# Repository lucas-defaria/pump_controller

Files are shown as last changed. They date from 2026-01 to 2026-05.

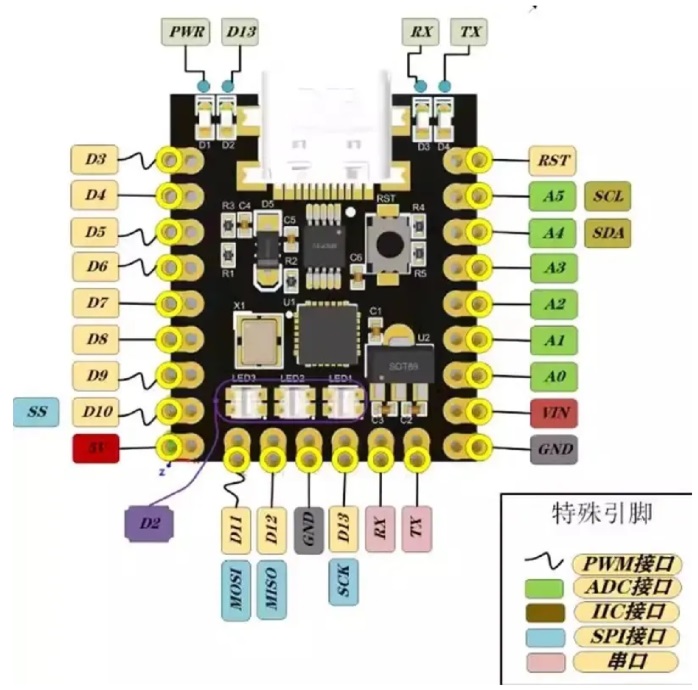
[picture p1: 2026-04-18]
hardware/EvoProject 1.0/0dc02c004ede8d6a5e8eab01bf967dcbca0c0e5b.jpeg

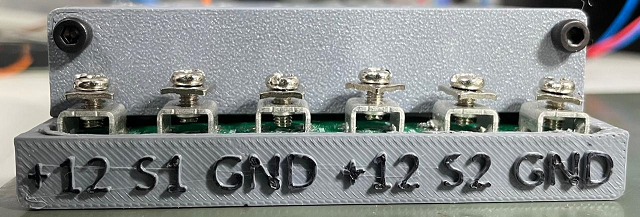
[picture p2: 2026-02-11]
saidas.png

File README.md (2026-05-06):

# PumpControl — Controle de Bomba de Combustível

Firmware para controle de bomba de combustível baseado em Arduino Nano, com dois modos de operação (MAP-based e slave por PWM externo) e proteção multinível por corrente, tensão e safety externa.

Este README descreve o estado atual do firmware no branch `main`.

## Visão geral

- **Modo MAP (default)**: pressão do MAP modulando duty entre 50% e 100% de Vsupply.
- **Modo slave (override)**: quando há PWM externo válido em D8, o duty externo é replicado nos outputs (anula o controle por MAP).
- **Proteção em 3 níveis** por corrente: NORMAL → FAULT → EMERGENCY.
- **Boot hold-off** de 2 s com motor OFF e inicialização defensiva (pinos em estado seguro antes de virar OUTPUT).
- **PWM de potência a 3.9 kHz** em Timer 0 (D5/D6), com compensação de timing em todo o código.

## Hardware

- **MCU**: Arduino Nano (ATmega328P @ 16 MHz)
- **Alimentação do módulo**: +5 V vindo da placa host entra no pino **5V (VOUT)** do Nano. **VIN desconectado** para evitar dropout do regulador interno (o DCDC da host já entrega 5 V regulado).
- **Power stage**: IRFB3077 como switch low-side, MBR30100 como freewheeling. Carga ligada entre VCC2 e PWM_OUT — o sinal medido no dreno é invertido em relação ao gate e só aparece quando há carga.
- **Driver de gate**: BC817 (NPN) + BC807 (PNP) — topologia inverte o sinal PWM, compensada em SW (`PWM_INVERTED_BY_HARDWARE = true`).
- **Sensores de corrente**: 2× **ACS758LCB-050B** (bidirecional ±50 A, 40 mV/A nominal). Correntes negativas (fluxo reverso) são clampadas a 0.
- **Sensor MAP**: MPX5700AP (pressão absoluta 15–700 kPa). Conversão para gauge subtraindo `ATMOSPHERIC_PRESSURE_BAR` (1.013 bar).
- **NTC 10 K** no dissipador, dividor com R19 (10 K) e R20 em série (alta impedância) para o ADC. C16 (4.7 μF) filtra.
- **Sense de Vsupply**: divisor 1:11 (R1=10 K, R2=1 K).
- **LED de status**: NeoPixel (1 LED) em D2.

## Pinout (Config.h)

| Pino | Função | Observações |
|---|---|---|
| A1 | NTC heatsink | Beta 3950, R25 = 10 K |
| A2 | Current Ch1 | ACS758LCB-050B |
| A3 | Current Ch2 | ACS758LCB-050B |
| A4 | MAP | MPX5700AP |
| A5 | Vsupply | Divisor 1/11 |
| D2 | NeoPixel | Status visual |
| D5 | PWM_OUT_2 | Timer 0 / OC0B |
| D6 | PWM_OUT_1 | Timer 0 / OC0A — movido de D3 (ver nota abaixo) |
| D7 | Safety input | OPTO output, ativo LOW (HIGH = OK) |
| D8 | PWM input externo | Slave mode (200–400 Hz) |
| A0 | AUX in | Reservado |

> **Por que D6 e D5 (Timer 0)** — o pino D11 (OC2A do Timer 2) é compartilhado com SPI/MOSI; quando o CAN/MCP2515 está ativo, ocorrem glitches periódicos no PWM em D3 (OC2B do mesmo Timer 2). Timer 0 não tem overlap com SPI, então mover ambas as saídas para D5/D6 elimina o problema.

> **R30 e R45 não populados** — D7 e D8 são apenas saídas dos OPTOs; não há caminho elétrico de retorno para a base de T4/T8. O Arduino é o **único driver** dos gates dos MOSFETs via D5/D6.

## PWM de potência

- **3.9 kHz** Phase-Correct PWM em Timer 0 (`16 MHz / (2 × 256 × 8) ≈ 3906 Hz`).
- Prescaler do Timer 0 alterado de 64 → 8 para atingir essa frequência.
- **Efeito colateral**: `millis()` e `delay()` rodam **8× mais rápido**. Todo código de timing usa o macro `MILLIS_COMPENSATED(ms)` (multiplica por `TIMER0_PRESCALER_FACTOR = 8`). `delayMicroseconds()` **não** é afetado.
- `PWM_INVERTED_BY_HARDWARE = true`: SW inverte o byte (`pwmValue = 255 - pwmValue`) antes do `analogWrite`, de forma que `duty = 1.0` corresponde a MOSFET ON (potência total).

## Modos de operação

### MAP mode (default)

Mapeamento linear entre pressão (gauge) e percentual da Vsupply:

| Pressão (bar gauge) | Saída |
|---|---|
| ≤ 0.4 (`MAP_BAR_LOW_SETPOINT`) | 50% Vsupply (`OUTPUT_PERCENT_MIN`) |
| 0.4 → 0.6 | interpolação linear |
| ≥ 0.6 (`MAP_BAR_HIGH_SETPOINT`) | 100% Vsupply (`OUTPUT_PERCENT_MAX`) |

Filtro EMA no MAP: `MAP_FILTER_ALPHA = 0.15`.

### Slave mode (PWM externo em D8)

Quando `ENABLE_EXTERNAL_PWM_MODE = true` e há sinal válido em D8, o controle por MAP é **sobrescrito**: o duty cycle medido na entrada vira o target dos outputs.

- Frequência válida: **200–400 Hz** (típico ~300 Hz)
- Timeout: **200 ms** sem pulso → volta para MAP
- Leitura via `pulseIn()` (pode bloquear até ~100 ms por amostra), uma medida por iteração do loop principal
- Linha de status no Serial muda para `*** EXTERNAL PWM MODE ***` com freq e duty medidos

## Proteção por corrente (3 níveis)

Estratégia: **nunca desligar totalmente em condição de fault** (motor sob carga seria danificado), exceto em EMERGENCY (curto/saturação).

| Nível | Faixa | Limite de tensão | Ação |
|---|---|---|---|
| **NORMAL** | < 40 A | 100% | Sem limitação |
| **FAULT** | ≥ 40 A | 50% | Reduz para mínimo seguro com rate limiting |
| **EMERGENCY** | ≥ 45 A | 0%* | Shutdown imediato, **bypassa rate limiting** e força `setDuty(0)` no main loop |

\* Se `ENABLE_EMERGENCY_SHUTDOWN = false`, EMERGENCY cai para 50% como fail-safe.

- Histerese: **2.5 A** para retornar ao nível anterior
- Decisão usa `max(I_ch1, I_ch2)` (qualquer canal acima do threshold dispara)
- Rate limiting normal: 0.05 por ciclo de 50 ms (≈ 1 s para varredura completa)
- Override de EMERGENCY no `loop()`: mesmo se source for slave, EMERGENCY força duty 0

## Proteção por tensão de alimentação

Adaptativa por queda percentual da Vsupply medida (lida em A5):

- **WARNING**: queda de 30%
- **CRITICAL**: queda de 50%
- Histerese: 0.5 V para evitar oscilação
- Faixa válida do sensor: 7.0–16.0 V (fora disso = sensor fault)

## Safety externa (D7)

- `ENABLE_EXTERNAL_SAFETY = true`
- `EXTERNAL_SAFETY_ACTIVE_HIGH = false` → **LOW = shutdown**, HIGH = OK (OPTO mantém HIGH em operação normal)
- **Bypassa rate limiting**: ação instantânea
- LED pisca azul (`updateExternalSafetyBlink`) enquanto ativo
- Skipa o restante do loop de controle (prioridade máxima)

## Sensor de corrente — calibração

ACS758LCB-050B (bidirecional, sensitivity nominal 40 mV/A):

- Calibração de slope feita em bancada (após filtro RC):
  - 1.32 A → 2.54 V
  - 2.30 A → 2.58 V
  - Slope = `(2.58 − 2.54) / (2.30 − 1.32) = 40.8 mV/A` ≈ nominal
- Vzero derivado do slope: **2.488 V @ 0 A** (offset Voe dentro do spec ±60 mV)
- Multi-amostragem: **32 samples × 50 μs ≈ 4.9 ms** (~19 ciclos de PWM a 3.9 kHz)
- EMA `CURRENT_FILTER_ALPHA = 0.05` (constante de tempo ~1 s a 20 Hz — agressivo para rejeitar ripple, lento o bastante para proteção)

## Temperatura (NTC 10K) — monitoramento

- Equação Beta: `1/T = 1/T25 + (1/β) · ln(R / R25)`, β = 3950
- Mesmo rail (+5 V) para divisor e ADC → `Vref` cancela: `R_NTC = R_PULLUP × adc / (1023 − adc)`
- Detecção de falha: temp fora de [-40, 150] °C indica sensor aberto/curto
- **Sem ação de proteção** — apenas leitura e log no status report

## LED de status (NeoPixel em D2)

| Cor | Significado |
|-----|---|
| Verde sólido | Normal (gradiente verde→vermelho conforme corrente sobe) |
| Vermelho 1 Hz | FAULT |
| Vermelho 5 Hz | EMERGENCY |
| Azul piscando | Safety externa ativa |

## Comunicação

- **Serial @ 115200 bps**:
  - Linha compacta a 20 Hz com modo (MAP/EXTERNAL PWM), pressão ou duty externo, target, Vsupply, I1, I2, voltage limit, nível de proteção
  - Relatório detalhado a 1 Hz com todas as métricas, fault counts e estado dos inputs digitais
- **CAN bus (MCP2515)**: stub presente (`g_can.poll()`), infra mínima — sem tráfego ativo nesta versão do `main`. Versão com CAN funcional segue em `develop-TempControl`.

## Sequência de boot

1. `PowerOutputs::begin()` força os pinos em estado seguro (HIGH = MOSFET OFF na topologia invertida) ainda como INPUT
2. Configura como OUTPUT após estabilização (100 μs)
3. Configura Timer 0 (Phase-Correct, prescaler 8) para 3.9 kHz
4. `setDuty(0)` + 100 ms de grace period
5. Inicialização dos sensores e da safety externa
6. **Hold-off de 2 s** com motor OFF (`delayMicroseconds(2_000_000)` — não afetado pelo prescaler)
7. Entra no loop normal

## Configuração — flags principais (Config.h)

| Flag | Default | Função |
|---|---|---|
| `ENABLE_HIGH_FREQ_PWM` | `true` | 3.9 kHz no Timer 0 |
| `PWM_INVERTED_BY_HARDWARE` | `true` | Compensa BC817+BC807 |
| `ENABLE_EMERGENCY_SHUTDOWN` | `true` | 0% em EMERGENCY (false = 50%) |
| `ENABLE_EXTERNAL_SAFETY` | `true` | D7 LOW desliga |
| `EXTERNAL_SAFETY_ACTIVE_HIGH` | `false` | Polaridade da safety |
| `ENABLE_EXTERNAL_PWM_MODE` | `true` | Slave mode em D8 |

Ajustes finos: setpoints de pressão (`MAP_BAR_*_SETPOINT`), thresholds de corrente (`CURRENT_THRESHOLD_*`), faixa válida do sensor (`VOLTAGE_*_VALID`), filtros EMA.

## Build

- Arduino IDE 1.8+ ou PlatformIO
- Lib: `Adafruit_NeoPixel`
- Board: Arduino Nano (ATmega328P, Old Bootloader)
- Sketch: `src/PumpControl/PumpControl.ino`

## Notas da PCB v1.0

- 5 V da host alimenta o Nano via pino 5V (VOUT); VIN deixado desconectado para evitar dropout do regulador interno
- Conectores CN4 e CN5 podem estar com pinagem invertida
- Sensor MAP: Vout é o **pino 1** (não pino 3)
- Pode ser necessário remover componentes do pino RESET durante gravação
- Trilha de 5 V do USB do Arduino deve ser cortada para evitar alimentação reversa
- PWM_OUT_1 movido de D3 → **D6** para resolver glitches por compartilhamento de Timer 2 com SPI

## Estrutura do firmware

```
src/PumpControl/
├── PumpControl.ino       — main loop, source select, override de EMERGENCY
├── Config.h              — todos os parâmetros de compile-time
├── MapSensor.{h,cpp}     — MPX5700AP, conversão absoluta → gauge, EMA
├── PowerOutputs.{h,cpp}  — Timer 0 PWM, inversão por HW, voltage limiting
├── CurrentSensor.{h,cpp} — ACS758LCB-050B, multi-sampling, EMA
├── PowerProtection.h     — máquina de estados NORMAL/FAULT/EMERGENCY
├── VoltageSensor.{h,cpp} — divisor 1:11, leitura de Vsupply
├── VoltageProtection.h   — proteção por queda percentual
├── TempSensor.h          — NTC 10K, equação Beta (monitoramento)
├── PwmInput.h            — pulseIn-based, slave mode em D8
├── StatusLed.h           — NeoPixel state machine
└── CanInterface.{h,cpp}  — stub MCP2515
```

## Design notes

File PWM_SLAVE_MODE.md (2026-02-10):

# Modo Slave PWM - Documentação

## Visão Geral

Foi implementado um modo secundário de operação onde a placa pode funcionar como "slave", reproduzindo um sinal PWM externo nas suas saídas, ao invés de usar o controle baseado no sensor MAP.

## Funcionamento

### Modo Normal (MAP-based)
- **Quando**: Nenhum sinal PWM válido detectado na entrada digital PIN 1 (D7)
- **Comportamento**: Sistema opera normalmente lendo o sensor MAP e controlando as bombas baseado na pressão medida
- **Este é o modo padrão quando não há sinal PWM**

### Modo Slave (PWM Replication)
- **Quando**: Sinal PWM válido detectado na entrada digital PIN 1 (D7)
- **Comportamento**: Sistema replica o duty cycle do PWM de entrada nas duas saídas
- **Transição automática**: Sistema detecta automaticamente quando há sinal PWM válido e muda para modo slave
- **Retorno automático**: Se o sinal PWM desaparecer por mais de 200ms, retorna ao modo normal MAP

## Características Técnicas

### Hardware
- **Pino de entrada**: D7 (PIN_DIG_IN_1 / Config::PIN_PWM_INPUT)
- **Frequência esperada**: 25Hz (aceita 15-35Hz)
- **Duty cycle**: 0-100% (variável)
- **Timeout**: 200ms sem pulso válido = sinal perdido

### Proteções Mantidas
Mesmo em modo slave, todas as proteções continuam ativas:
- ? Proteção de corrente (current protection)
- ? Proteção de tensão (voltage protection)
- ? External safety input (D8)
- ? Rate limiting
- ? Status LED indicando corrente e falhas

### Prioridade de Controle
1. **MAIS ALTA**: External Safety Input (D8) - desliga tudo imediatamente
2. **MÉDIA**: PWM Slave Mode - se sinal válido presente
3. **NORMAL**: MAP-based Control - modo padrão quando não há sinal PWM

## Configuração

Todas as configurações estão em [Config.h](Config.h):

```cpp
// Habilitar/desabilitar modo slave
constexpr bool ENABLE_PWM_SLAVE_MODE = true;

// Pino de entrada PWM
constexpr uint8_t PIN_PWM_INPUT = PIN_DIG_IN_1;  // D7

// Faixa de frequência válida (Hz)
constexpr float PWM_INPUT_FREQ_MIN = 15.0f;
constexpr float PWM_INPUT_FREQ_MAX = 35.0f;

// Timeout para perda de sinal (ms)
constexpr unsigned long PWM_INPUT_TIMEOUT_MS = 200;
```

## Detalhes de Implementação

### Classe PwmInput

Nova classe criada em [PwmInput.h](PwmInput.h) que implementa:
- Leitura precisa de PWM por detecção de bordas (rising/falling edge)
- Cálculo automático de frequência e duty cycle
- Validação de sinal (frequência dentro da faixa esperada)
- Timeout automático quando sinal desaparece
- Usa `micros()` para máxima precisão de timing

### Métodos Principais

```cpp
g_pwmInput.update();              // Atualizar leitura (chamar frequentemente)
g_pwmInput.isSignalValid();       // Verificar se sinal PWM válido presente
g_pwmInput.getDutyCycle();        // Obter duty cycle (0.0 a 1.0)
g_pwmInput.getFrequency();        // Obter frequência detectada (Hz)
```

## Output Serial

### Modo Normal
```
P:0.45bar | Vs:12.3V | T%:85% | Vo:10.5V | I1:12.3A | I2:11.8A | Lim:100% | NORMAL
```

### Modo Slave (novo)
```
*** SLAVE MODE *** | PWM In:75.5% @ 25.2Hz | Vs:12.3V | Vo:9.3V | I1:12.3A | I2:11.8A | Lim:100% | NORMAL
```

### Status Report Detalhado
Quando em modo slave, o status report mostra informações adicionais:
```
PWM Slave Mode:  *** ACTIVE ***
  Input Duty:    75.5 %
  Input Freq:    25.12 Hz
  Period:        39.81 ms
  High Time:     30.06 ms
```

## Testes Recomendados

1. **Teste sem sinal**: Verificar que sistema opera normalmente em modo MAP
2. **Teste com PWM 25Hz**: Aplicar PWM de 25Hz e verificar mudança para modo slave
3. **Teste de duty cycle variável**: Variar duty cycle de 10% a 90% e verificar que saídas acompanham
4. **Teste de timeout**: Remover sinal PWM e verificar retorno ao modo MAP após 200ms
5. **Teste de proteções**: Verificar que proteções de corrente/tensão continuam funcionando em modo slave
6. **Teste de frequência fora da faixa**: Aplicar PWM de 10Hz ou 40Hz e verificar que sistema ignora (permanece em modo MAP)

## Notas Importantes

- ?? **Não altera comportamento padrão**: Sistema continua funcionando normalmente quando não há sinal PWM
- ?? **Detecção automática**: Não precisa configurar manualmente, sistema detecta presença de sinal
- ?? **Proteções sempre ativas**: Mesmo em modo slave, todas as proteções (corrente, tensão) permanecem operantes
- ?? **External safety tem prioridade**: Input de segurança externa (D8) sempre tem prioridade sobre tudo
- ? **Transição suave**: Mudança entre modos é suave graças ao rate limiting existente
- ? **Compatível com timer modificado**: Usa `micros()` que não é afetado pela modificação do Timer 0

## Arquivos Modificados

1. **PwmInput.h** (novo) - Classe para leitura de PWM
2. **Config.h** - Adicionadas configurações de PWM slave
3. **PumpControl.ino** - Integração do modo slave no loop principal

## Histórico

- **2025-02-02**: Implementação inicial do modo slave PWM

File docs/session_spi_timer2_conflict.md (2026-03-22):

# Sessão: Conflito SPI/Timer 2 - PWM D3 resetando periodicamente

## Problema
Com o CAN bus ativo (MCP2515 via SPI), a saída PWM no pino D3 (OC2B, Timer 2) reseta para 0% duty periodicamente. D5 (OC0B, Timer 0) funciona perfeitamente com o mesmo valor de PWM.

## Causa raiz identificada
**SPI e Timer 2 compartilham o pino D11 (PB3 = MOSI = OC2A).** Transações SPI do MCP2515 interferem com o Timer 2, corrompendo a saída hardware OC2B no D3. No PumpController original, o CanInterface era um stub vazio sem comunicação SPI real - por isso nunca houve problema.

### Evidências
- Comentando `g_can.poll()`: D3 funciona perfeitamente (sem SPI = sem interferência)
- D5 (Timer 0) nunca apresenta o problema (Timer 0 não compartilha pinos com SPI)
- Com dados CAN reais a 50Hz: problema menos perceptível mas ainda presente no osciloscópio
- Com SavvyCAN a 500ms: problema visível com ciclo bem definido

## Tentativas de solução

### 1. Mover PWM para Timer 0 (D6) - FUNCIONA mas hardware é fixo
- Alterar `PIN_PWM_OUT_1 = 6` (OC0A, Timer 0) no Config.h
- Ambas saídas ficariam no Timer 0, sem conflito com SPI
- **Descartado**: PCB tem trilhas fixas em D3 e D5

### 2. Desabilitar SPI entre transações - PARCIAL
```cpp
// Em CanInterface::poll():
SPCR |= _BV(SPE);   // Habilita SPI antes
// ... checkReceive / readMsgBuf ...
SPCR &= ~_BV(SPE);  // Desabilita SPI depois
```
- Reduziu o problema (dados reais a 50Hz pareciam OK visualmente)
- Ainda apresenta glitches breves durante a transação SPI (~40µs)

### 3. Restaurar COM2B1 após poll - PARCIAL
```cpp
TCCR2A |= _BV(COM2B1);  // Reconecta Timer 2 ao D3 após SPI
```
- Combinado com solução 2, ajudou mas não eliminou completamente

### 4. Software PWM via ISR do Timer 2 - IMPLEMENTADO (ainda com problema de reset)
Abordagem: não usar saída hardware OC2B, controlar D3 via PORTD nas ISRs do Timer 2.

**PowerOutputs.h:**
- `extern volatile bool g_timer2_softpwm;` (declaração)
- Em `begin()`: `TCCR2A &= ~(_BV(COM2B1) | _BV(COM2B0));` desconecta OC2B
- Em `begin()`: `TIMSK2 |= _BV(OCIE2B) | _BV(TOIE2);` habilita interrupções
- Em `setDuty()`: para D3, escreve OCR2B e controla flag ao invés de analogWrite

**PumpControl.ino:**
```cpp
volatile bool g_timer2_softpwm = false;

ISR(TIMER2_OVF_vect) {
    // BOTTOM: set D3 HIGH (início do ciclo PWM)
    if (g_timer2_softpwm) {
        PORTD |= _BV(PD3);
    }
}

ISR(TIMER2_COMPB_vect) {
    // Compare match (up e down): toggle D3
    if (g_timer2_softpwm) {
        PORTD ^= _BV(PD3);
    }
}
```

**Lógica do toggle:**
- BOTTOM → OVF ISR → força HIGH
- Up-count match → COMPB ISR → toggle HIGH→LOW
- Down-count match → COMPB ISR → toggle LOW→HIGH
- Replica comportamento Phase-Correct PWM não-invertido

**Status:** Compila com erro de definição múltipla da variável `g_timer2_softpwm` (resolvido com `extern`), mas o **problema de reset do PWM persiste**. A interferência do SPI pode estar afetando o próprio contador do Timer 2 (TCNT2), não apenas a saída OC2B.

## Arquivos modificados nesta sessão

| Arquivo | Mudanças |
|---|---|
| `Config.h` | `TEMP_FAN_OFF_C`: 95→50, `PIN_CAN_CS`: 10→9 |
| `CanInterface.cpp` | Removido workaround SPI enable/disable (substituído por ISR) |
| `PowerOutputs.h` | Software PWM via ISR para D3, `extern volatile bool g_timer2_softpwm` |
| `PumpControl.ino` | Adicionadas ISRs Timer 2 (OVF + COMPB), definição `g_timer2_softpwm` |

## Próximos passos a investigar

1. **Verificar se SPI corrompe TCNT2** (não apenas OC2B): se o contador do Timer 2 é afetado, as ISRs também terão timing errado
2. **Mover D3 para Timer 1**: usar ICR1 como TOP e OC1A/OC1B - Timer 1 não compartilha pinos com SPI. Mas D9 (OC1A) é CAN CS e D10 (OC1B) tem pull-down do módulo
3. **Timer 1 com ISR para D3**: usar Timer 1 compare interrupt para gerar software PWM no D3, eliminando completamente o Timer 2 da equação
4. **Verificar se NeoPixel (D2, PORTD) contribui**: NeoPixel escreve PORTD inteiro durante show(), D3 é PD3. Com COM2B desconectado e ISR controlando via PORTD, o NeoPixel pode sobrescrever o estado de D3
5. **Testar desabilitando NeoPixel**: comentar `g_statusLed.updateFromCurrent()` para isolar se o NeoPixel está sobrescrevendo D3 via PORTD

### Hipótese mais provável: conflito NeoPixel + Software PWM
Com a solução de ISR (software PWM via PORTD), o NeoPixel `show()` pode estar causando o problema:
- NeoPixel D2 está no PORTD (PD2)
- `show()` faz `hi = PORTD | pinMask; lo = PORTD & ~pinMask;` e depois escreve `hi`/`lo` repetidamente para PORTD inteiro via assembly
- Com hardware OC2B, o timer overrides PORTD → NeoPixel não afeta D3
- Com software PWM via PORTD, NeoPixel `show()` pode sobrescrever PD3 durante os ~30µs de transmissão (interrupts desabilitados com `cli()`)
- **Isso causaria glitches no D3 a cada chamada de `updateFromCurrent()`** (a cada 50ms do loop)

## Contexto do hardware
- Arduino Nano (ATmega328P)
- MCP2515 + TJA1050 (CAN bus 500kbps, cristal 8MHz)
- SPI: MOSI=D11, MISO=D12, SCK=D13, CS=D9
- PWM saídas: D3 (Timer 2 OC2B), D5 (Timer 0 OC0B)
- NeoPixel: D2 (PORTD)
- Driver inversor: BC817+BC807 (PWM_INVERTED_BY_HARDWARE = true)
- Timer 0 prescaler: 64→8 (millis() 8x mais rápido, compensado com MILLIS_COMPENSATED)
- PWM frequência: 3.9kHz Phase-Correct

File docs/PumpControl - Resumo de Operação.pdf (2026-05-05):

# Modulo PumpControl - Resumo de Operacao

Documento de referencia para teste em campo. Numeracao dos pinos conforme conector Molex Mini-Fit Jr. de 16 vias da traseira do modulo.

## 1. Modo MAP (operacao padrao)

O modulo le o sensor de pressao MPX5700AP e ajusta a saida em funcao da pressao (em bar relativos a atmosfera):

Pressao lida | Saida na bomba
≤ 0,4 bar | 50% da tensao de alimentacao
0,6 bar ou mais | 100% da tensao de alimentacao
Entre 0,4 e 0,6 bar | Rampa linear entre 50% e 100%

A saida e proporcional a tensao medida (nao fixa em 12 V), entao o modulo se adapta automaticamente em qualquer faixa de 8 V a 14,5 V.

## 2. Modo Slave (PWM externo)

O modulo monitora o pino 13 do conector.
Se receber um sinal PWM valido entre 200 e 400 Hz (tipico 300 Hz, nivel logico 0–12 V), automaticamente sai do modo MAP e passa a copiar o duty cycle desse sinal nas duas saidas para a bomba.
Se o sinal sumir por mais de 200 ms, o modulo volta sozinho ao modo MAP.
Nao ha chave fisica: o "switch" e automatico, baseado na presenca/ausencia do PWM no pino 13 .

## 3. Protecoes (em ordem de prioridade)

05/05/2026, 20:13 | PumpControl - Resumo de Operação

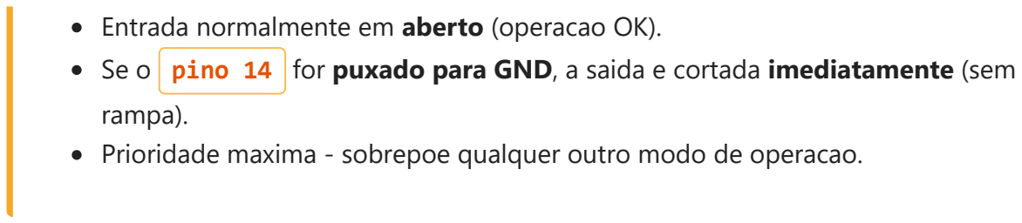
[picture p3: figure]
rampa).

Entrada normalmente em aberto (operacao OK).
Se o pino 14 for puxado para GND, a saida e cortada imediatamente (sem

Prioridade maxima - sobrepoe qualquer outro modo de operacao.

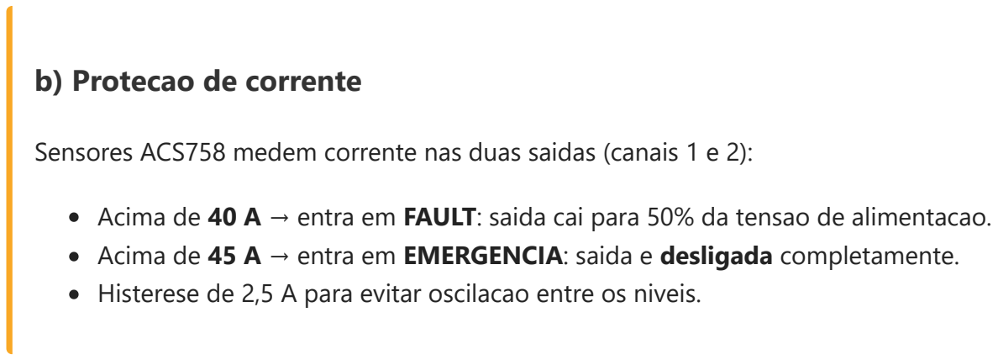
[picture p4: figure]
b) Protecao de corrente

Sensores ACS758 medem corrente nas duas saidas (canais 1 e 2):

Acima de 40 A → entra em FAULT: saida cai para 50% da tensao de alimentacao. Acima de 45 A → entra em EMERGENCIA: saida e desligada completamente. Histerese de 2,5 A para evitar oscilacao entre os niveis.

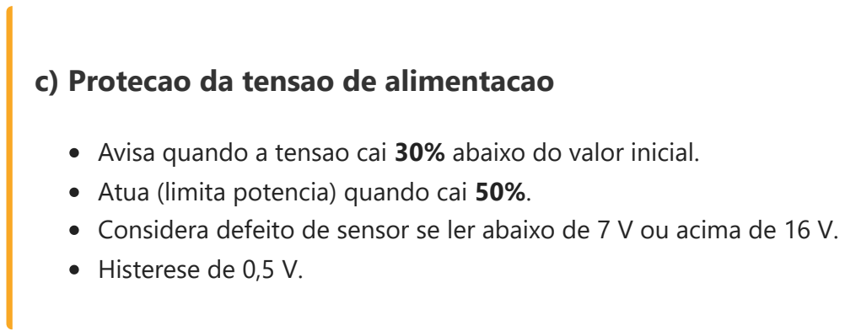
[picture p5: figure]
c) Protecao da tensao de alimentacao; Atua (limita potencia) quando cai 50%.; Histerese de 0,5 V.

Avisa quando a tensao cai 30% abaixo do valor inicial.

Considera defeito de sensor se ler abaixo de 7 V ou acima de 16 V.

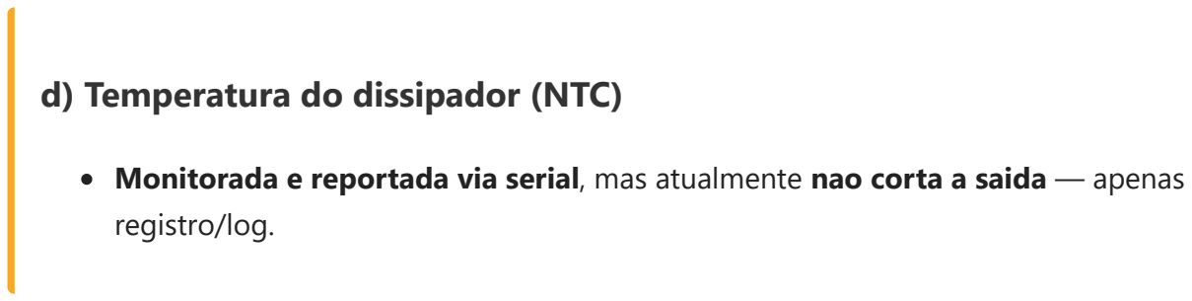
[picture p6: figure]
d) Temperatura do dissipador (NTC); registro/log.

Monitorada e reportada via serial, mas atualmente nao corta a saida — apenas

## 4. Indicacao no LED (NeoPixel)

Verde → operacao normal (cor passa de verde para vermelho conforme a corrente sobe). Vermelho piscando 1 Hz → FAULT de corrente (acima de 40 A).
Vermelho piscando 5 Hz → EMERGENCIA (acima de 45 A).
Azul piscando → Safety externa ativa ( pino 14 em GND).

## 5. Partida segura

file:///C:/Users/lucas.faria/Documents/Proj/pump_controller/docs/resumo_cliente.html | 2/4

Ao energizar, a saida fica forcada em 0% por aproximadamente 2 segundos enquanto os sensores estabilizam.
So depois desse intervalo o controle normal entra em operacao.

## 6. Pinagem do conector (vista traseira)

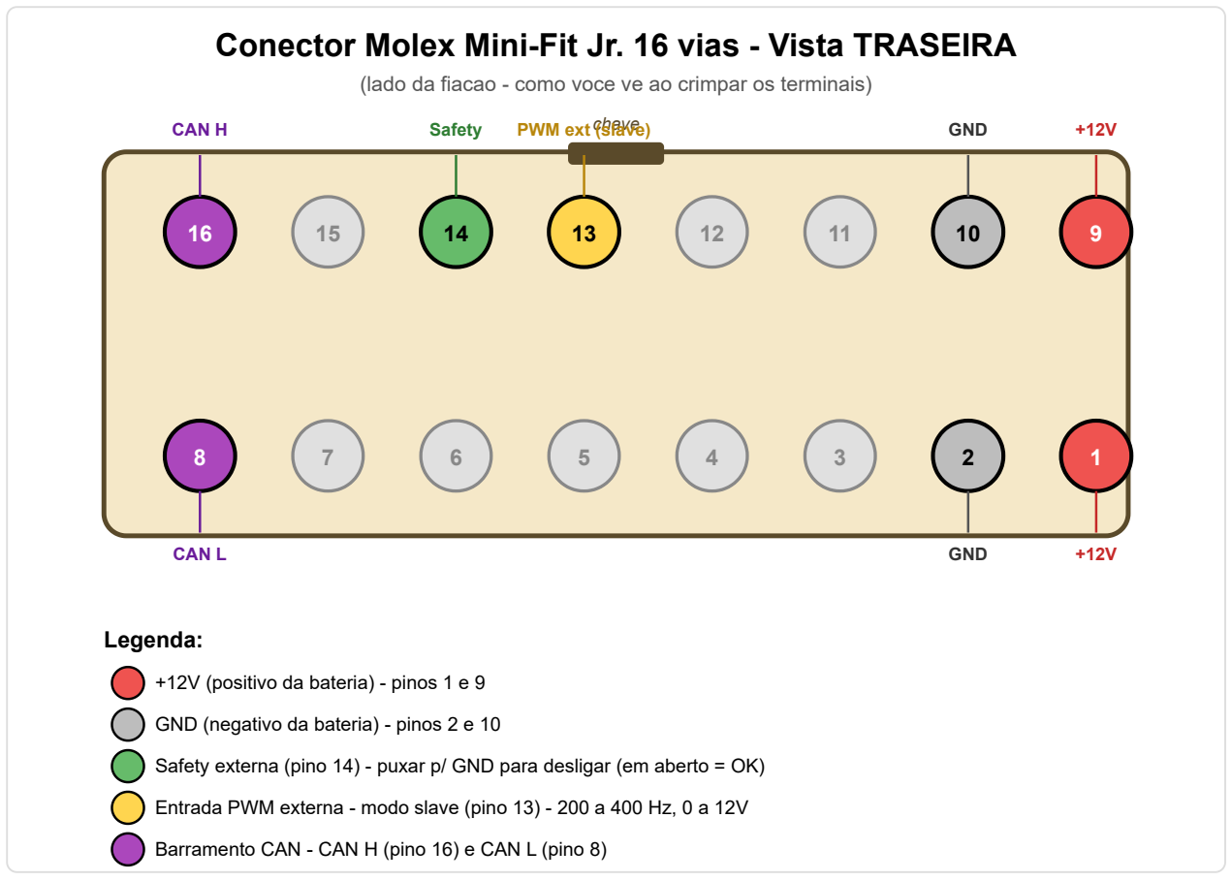
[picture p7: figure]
chave; CAN H; Safety; PWM ext (slave); GND; CAN L; Legenda:

Conector Molex Mini-Fit Jr. 16 vias - Vista TRASEIRA

(lado da fiacao - como voce ve ao crimpar os terminais)

+12V (positivo da bateria) - pinos 1 e 9

GND (negativo da bateria) - pinos 2 e 10

Safety externa (pino 14) - puxar p/ GND para desligar (em aberto = OK)

Entrada PWM externa - modo slave (pino 13) - 200 a 400 Hz, 0 a 12V

Barramento CAN - CAN H (pino 16) e CAN L (pino 8)

Tabela resumida

Pino | Funcao
1, 9 | +12V (positivo da bateria)
2, 10 | GND (negativo da bateria)

8 CAN L

13 Entrada PWM externa (modo slave)

14 Safety externa (em aberto = OK / GND = desliga)

16 CAN H

file:///C:/Users/lucas.faria/Documents/Proj/pump_controller/docs/resumo_cliente.html | 3/4

Pino | Funcao
3, 4, 5, 6, 7, 11, 12, 15 | Nao utilizados (deixar desconectados)

PumpControl - Documento de referencia para teste em campo

file:///C:/Users/lucas.faria/Documents/Proj/pump_controller/docs/resumo_cliente.html | 4/4

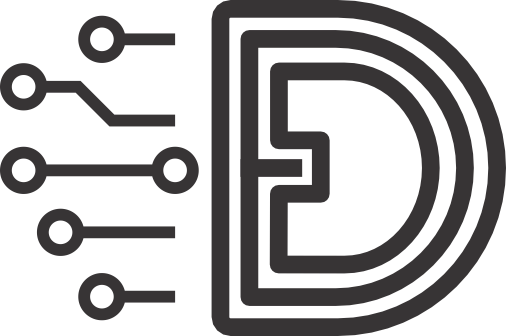
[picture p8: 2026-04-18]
hardware/EvoProject 1.0/Sem título-1.png

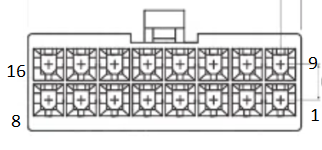
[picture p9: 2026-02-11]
image.png

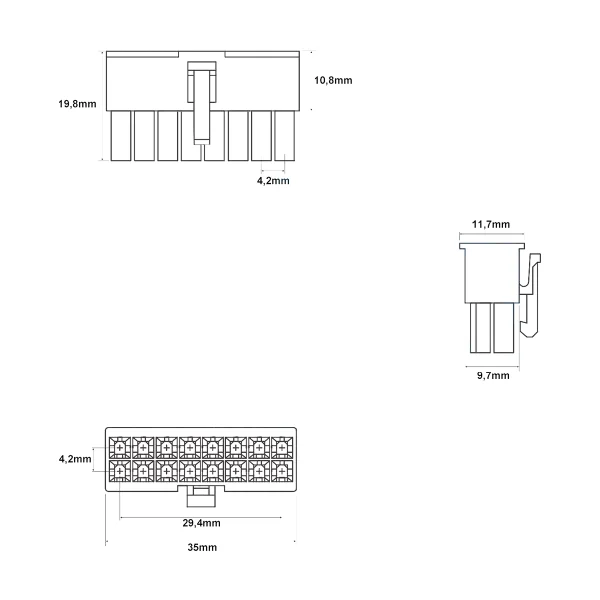
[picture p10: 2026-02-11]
02-conector-mini-fit-macho-hm051-2x8-16-vias.webp

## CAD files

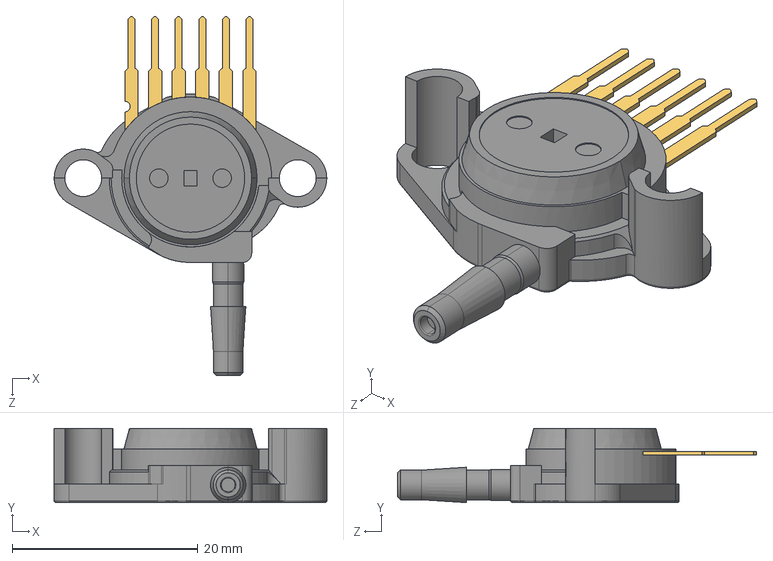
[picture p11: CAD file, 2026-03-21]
hardware/EvoProject 1.0/MPX5700AP.stp
29.4 x 8.01 x 38.7 mm

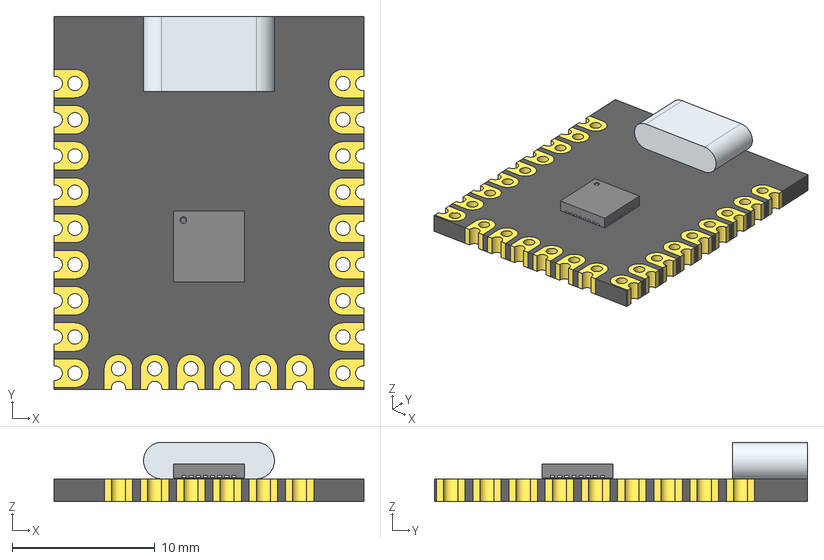
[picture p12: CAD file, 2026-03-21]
hardware/EvoProject 1.0/Arduino_Nano_SuperMini.stp
21.7 x 26.2 x 4.16 mm

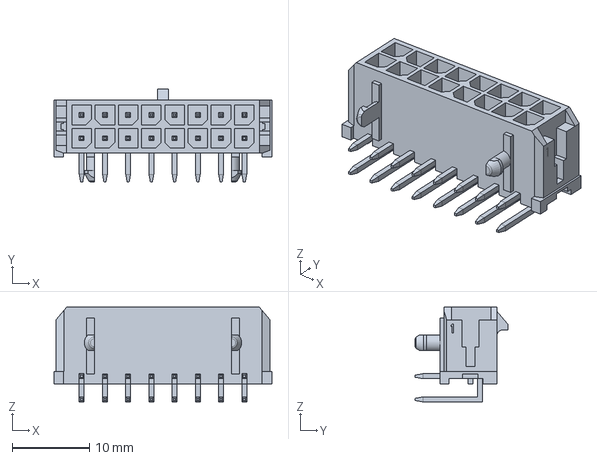
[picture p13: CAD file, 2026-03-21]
hardware/EvoProject 1.0/430451600.stp
28.1 x 11.9 x 12.2 mm

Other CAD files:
hardware/EvoProject 1.0/Arduino_Nano_SuperMicro.step

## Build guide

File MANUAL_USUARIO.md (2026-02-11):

# Manual do Usuário - PumpControl

## Especificações Técnicas

### Alimentação
- **Tensão de entrada:** 8-16V DC (sistema automotivo)
- **Consumo:** Variável conforme carga conectada

### Sensor de Pressão (MAP)
- **Range de operação:** 15-700 kPa absoluto (0.15 - 7bar) (gauge/relativo)
- **Tipo:** MPX5700AP (pressão absoluta, convertida para gauge)

### Saídas PWM
- **Canais:** 2 saídas independentes
- **Controle:** Percentual da tensão de alimentação
  - Pressão baixa (0.4 bar): 70% da tensão de entrada
  - Pressão alta (0.6 bar): 100% da tensão de entrada
  - Valores intermediários: interpolação linear

### Monitoramento de Corrente
- **Canais:** 2 sensores independentes (ACS772LCB-050B)
- **Range:** 0-50A Maxima medida pelo sensor por canal (unidirecional)

---

## Conector de Interface



### Pinagem do Conector - vista traseira

| Pino | Função |
|---|---|
| 1 | VCC (Alimentação +8-16V) |
| 2 | GND (Terra) |
| 3 | |
| 4 | |
| 5 | |
| 6 | |
| 7 | |
| 8 | |
| 9 | |
| 10 | |
| 11 | |
| 12 | |
| 13 | |
| 14 | |
| 15 | Desliga saída (Safety) aciona por negativo |
| 16 |  |

saidas

#### +12 = +Bateria
#### S1 S2 = Saída para bomba 1 e 2 - acionamento por negativo
#### GND = Negativo bateria
---

## Sistema de Proteção por Corrente

O sistema possui proteção progressiva que **nunca desliga completamente** a bomba (crítico para motor em funcionamento).

### Níveis de Proteção

| Corrente | Nível | Ação | Redução de Potência |
|---|---|---|---|
| 0-25A | **NORMAL** | Operação normal | 0% (potência plena) |
| 25-30A | **WARNING** | Alerta inicial | 30% de redução |
| 30-35A | **HIGH** | Corrente alta | 40% de redução |
| 35-40A | **CRITICAL** | Corrente crítica | 50% de redução |
| >40A | **FAULT** | Falha detectada | 50% mantido (mínimo seguro) |
| >45A | **EMERGENCY** | Emergência | Desligamento completo* |

> *EMERGENCY: Indica curto-circuito ou sobrecarga severa (sensor próximo ao limite de 50A)

---

## Indicação Visual - LED RGB

O LED indica o estado do sistema em tempo real pela cor e comportamento:

### Cores Sólidas (operação normal)
| Cor | Significado |
|-----|---|
| ?? **Verde** | Corrente baixa (0-25A) - operação normal |
| ?? **Verde?Amarelo** | Corrente moderada (25-30A) - entrando em warning |
| ?? **Amarelo?Laranja** | Corrente elevada (30-35A) - proteção ativa |
| ?? **Laranja?Vermelho** | Corrente alta (35-40A) - proteção crítica |

### Piscando (situações críticas)
| Comportamento | Significado | Ação Necessária |
|---|---|---|
| ?? **Pisca lento** (1Hz) | FAULT - Corrente >40A | Verificar carga/fiação |
| ?? **Pisca rápido** (5Hz) | EMERGENCY - Corrente >45A | Verificar curto-circuito |
| ?? **Pisca azul** (2Hz) | Desligamento por segurança externa | Verificar entrada D8 |

---

## Entrada de Segurança Externa Pino 15

### Função
Permite que sistemas externos (ECU, relé de segurança, etc.) desliguem imediatamente as saídas.

### Configuração
- **Pino:** 15 (ativo em LOW - pull-up interno)
- **Ação:** Quando ativada, força saídas para 0V imediatamente
- **Indicação:** LED pisca em azul enquanto ativa

### Comportamento
- Quando a entrada de segurança é acionada:
  1. Saídas PWM vão para 0% instantaneamente (sem rampa)
  2. LED pisca em azul
  3. Mensagem no serial: "EXTERNAL SAFETY ACTIVE"
  4. Sistema retoma operação normal quando entrada é liberada

---

---

## Observações Importantes

### ?? Proteção Crítica
- O sistema **NUNCA** desliga completamente a bomba em níveis NORMAL-FAULT
- Apenas em EMERGENCY (>45A) ocorre desligamento completo
- Proteção progressiva reduz corrente gradualmente

### ?? Operação Normal
- LED verde = tudo OK
- Transição de cores = sistema adaptando à carga
- Corrente típica: 15-25A em operação normal

### ?? Atenção Necessária
- LED piscando vermelho = verificar carga e fiação
- LED piscando azul = entrada de segurança ativa
- Corrente >30A = investigar causa

### ?? Adaptação Automática
- Sistema ajusta saída baseado em:
  1. Pressão MAP (0.4-0.6 bar)
  2. Tensão de alimentação (8-16V)
  3. Corrente monitorada (proteção)
  
- Saída é sempre um **percentual da tensão de entrada**
- Exemplo: 80% em 12V = 9.6V / 80% em 14V = 11.2V

---

## Resumo - O que Observar

? **Normal:** LED verde sólido, corrente <25A  
?? **Atenção:** LED amarelo/laranja, corrente 25-35A  
?? **Crítico:** LED vermelho ou piscando, corrente >35A  
?? **Segurança:** LED azul piscando, entrada D8 ativa

---

*Versão do firmware: Baseada em Config.h com proteção progressiva*

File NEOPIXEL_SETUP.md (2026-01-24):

# Configuração do LED NeoPixel - Status Visual

## Descrição
O sistema agora inclui um LED NeoPixel RGB no pino D2 para indicação visual do estado de carga do motor baseado na pressão MAP.

### Indicação de Cores:
- **?? VERDE**: Baixa carga (MAP ? 0.2 bar)
- **?? AMARELO/LARANJA**: Carga média (MAP entre 0.2 e 0.4 bar) - transição gradual
- **?? VERMELHO**: Alta carga (MAP ? 0.4 bar - setpoint superior)

A cor muda gradualmente entre verde e vermelho conforme a pressão MAP aumenta, proporcionando feedback visual em tempo real da carga do motor.

## Hardware

### Conexões:
- **Pino D2**: Conectado ao DATA IN do LED NeoPixel
- **5V**: Alimentação do NeoPixel
- **GND**: Terra comum

### LED Suportado:
- WS2812B / NeoPixel compatível
- Configurado para 1 LED (pode ser ajustado em Config.h)

## Instalação da Biblioteca

### Método 1: Arduino IDE
1. Abra o Arduino IDE
2. Vá em **Sketch** ? **Include Library** ? **Manage Libraries...**
3. Pesquise por **"Adafruit NeoPixel"**
4. Clique em **Install** na biblioteca "Adafruit NeoPixel" by Adafruit
5. Aguarde a instalação completar

### Método 2: PlatformIO
Adicione ao seu `platformio.ini`:
```ini
lib_deps =
    adafruit/Adafruit NeoPixel@^1.12.0
```

## Arquivos Modificados/Criados

### Novos Arquivos:
- `StatusLed.h` - Classe de controle do LED NeoPixel

### Arquivos Modificados:
- `Config.h` - Adicionadas configurações:
  - `PIN_STATUS_LED` (D2)
  - `STATUS_LED_COUNT` (1)
  - `LED_BRIGHTNESS` (50 = ~20% do brilho máximo)
  
- `PumpControl.ino`:
  - Adicionado include `StatusLed.h`
  - Criada instância global `g_statusLed`
  - Inicialização no `setup()`
  - Atualização no `loop()` a cada ciclo (20Hz)

## Configuração

Todas as configurações estão em `Config.h`:

```cpp
// Pino do LED NeoPixel
constexpr uint8_t PIN_STATUS_LED = 2;  // D2

// Quantidade de LEDs na tira/anel
constexpr uint16_t STATUS_LED_COUNT = 1;

// Brilho (0-255, recomendado 30-100)
constexpr uint8_t LED_BRIGHTNESS = 50;
```

## Como Funciona

A classe `StatusLed` utiliza os mesmos setpoints de pressão MAP definidos em `Config.h`:
- `MAP_BAR_LOW_SETPOINT` (0.2 bar) - Verde
- `MAP_BAR_HIGH_SETPOINT` (0.4 bar) - Vermelho

Entre esses valores, o LED faz uma interpolação linear:
- Componente **RED**: Aumenta de 0 para 255
- Componente **GREEN**: Diminui de 255 para 0
- Componente **BLUE**: Permanece em 0

## Solução de Problemas

### LED não acende:
1. Verifique as conexões (DATA, 5V, GND)
2. Confirme que a biblioteca Adafruit NeoPixel está instalada
3. Verifique se o pino D2 não está sendo usado por outra função
4. Teste aumentar `LED_BRIGHTNESS` para 100 em Config.h

### LED com cor errada:
1. Alguns NeoPixels usam ordem diferente (RGB vs GRB)
2. Modifique em `StatusLed.h` linha 13:
   ```cpp
   // Tente trocar NEO_GRB por NEO_RGB se as cores estiverem trocadas
   : _strip(numPixels, pin, NEO_GRB + NEO_KHZ800) {}
   ```

### LED piscando/instável:
1. Adicione um capacitor 1000µF entre 5V e GND perto do LED
2. Adicione um resistor 470? entre D2 e DATA IN do LED

## Personalização

### Mudar cores:
Edite o método `updateFromPressure()` em `StatusLed.h`:
```cpp
// Exemplo: Azul para baixa carga, Amarelo para alta
if (pressureBar <= pLow) {
    red = 0; green = 0; blue = 255;  // Azul
} 
else if (pressureBar >= pHigh) {
    red = 255; green = 255; blue = 0;  // Amarelo
}
```

### Múltiplos LEDs:
Altere em `Config.h`:
```cpp
constexpr uint16_t STATUS_LED_COUNT = 8;  // Para tira com 8 LEDs
```

## Referências
- [Adafruit NeoPixel Library](https://github.com/adafruit/Adafruit_NeoPixel)
- [NeoPixel Überguide](https://learn.adafruit.com/adafruit-neopixel-uberguide)

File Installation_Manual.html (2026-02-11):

# Manual de Instalação

PumpControl - Controlador de Bomba de Combustível

Versão 2.0 | Janeiro 2026

## 1. Especificações do Sistema

### Características Principais

- Tensão de operação: 8 a 16V DC (12V nominal)
- Corrente máxima: 50A por canal (2 canais independentes)
- Controle: PWM 3.9 kHz (silencioso)
- Proteção: Multinível progressiva (nunca desliga totalmente)
- Indicação: LED RGB de status
- Temperatura: -20°C a +85°C

### O que o sistema faz

- ? Controla potência da bomba baseado na pressão do motor (sensor MAP)
- ? Reduz automaticamente potência se corrente ficar alta (proteção)
- ? Monitora tensão da bateria e ajusta automaticamente
- ? Indica estado via LED colorido
- ? Permite desligamento remoto (entrada D7)

## 2. Pinagem e Conexões

### Conexões Principais

Conexão | Descrição | Cabo Recomendado
+12V (Alimentação) | Positivo da bateria (pós-chave) | 4 AWG (25mm²), com fusível 60A
GND (Terra) | Negativo - chassi limpo | 4 AWG (25mm²)
Bomba 1 (+) | Positivo bomba canal 1 | 10 AWG (6mm²), com fusível 60A
Bomba 2 (+) | Positivo bomba canal 2 | 10 AWG (6mm²), com fusível 60A

### Sensores (já soldados na placa)

Sensor | Pinos | Conexão
MAP Sensor (MPX5700AP) | 3 fios | • Vermelho: +5V • Preto: GND • Amarelo: Sinal (para A4) • Mangueira: Coletor admissão
Corrente Ch1/Ch2 (ACS772LCB-050B) | Soldados | Passar cabo da bomba pelo centro (seta indica direção corrente)

### Entrada Opcional

Pino | Função | Uso
D7 | Desligamento externo | +5V = desliga bomba 0V = opera normal (conectar à ECU se disponível)

## 3. Sistema de Proteção

### Proteção por Corrente

O sistema NUNCA desliga completamente a bomba (perigoso para o motor). Reduz potência progressivamente:

Nível | Corrente | Ação | LED
NORMAL | 0 - 25A | Sem limitação (100%) | Verde
WARNING | 25 - 30A | Reduz para 70% | Amarelo
HIGH | 30 - 35A | Reduz para 60% | Laranja
CRITICAL | 35 - 40A | Reduz para 50% | Vermelho
FAULT | 40 - 45A | Mantém 50% (mínimo) | Vermelho
EMERGENCY | > 45A | Desliga total (configurável) | Vermelho

LED Azul piscando: Sistema inicializando (primeiros 2 segundos)

### Proteção por Tensão

- Detecta quedas de tensão da bateria
- Reduz potência automaticamente para proteger sistema elétrico
- Se tensão cai 30%: modo WARNING
- Se tensão cai 50%: modo CRITICAL

## 4. Procedimento de Instalação

Desconecte o terminal NEGATIVO da bateria antes de iniciar! Aguarde 5 minutos antes de trabalhar no sistema.

### Passo 1: Montagem Mecânica

- ?? Escolha local protegido de calor, água e vibração excessiva
- ?? Distância mínima 50cm de coletor/turbo
- ?? Fixe com 4 parafusos M3/M4
- ?? LED deve ficar visível

### Passo 2: Sensor MAP

- ?? Instale no coletor de admissão (após borboleta)
- ?? Use mangueira silicone 4-6mm (máx 1 metro)
- ?? Fixe sensor com conector para baixo (evita água)
- ?? Conecte 3 fios: Vermelho (+5V), Preto (GND), Amarelo (sinal)

PCB v1.0: Atenção à pinagem! Pino 1 do sensor = Vout (amarelo). Conectores podem estar invertidos - verifique com multímetro.

### Passo 3: Cabos de Potência

- ? +12V: Bateria ? Fusível 60A ? Módulo (cabo 4 AWG / 25mm²)
- ? GND: Módulo ? Chassi limpo (cabo 4 AWG / 25mm²)
- ? Bomba 1: Módulo saída 1 ? Fusível 60A ? Bomba (+)
- ? Bomba 2: Módulo saída 2 ? Fusível 60A ? Bomba (+)
- ? GND Bombas: Bombas (-) ? Chassi

OBRIGATÓRIO: Fusíveis de 60A em TODAS as linhas de potência. Usar terminais e conexões apropriados para corrente.

### Passo 4: Sensores de Corrente

- Os sensores já estão soldados na placa
- Passar cabo POSITIVO da bomba pelo centro do sensor
- Seta no sensor indica direção do fluxo de corrente (bateria ? bomba)
- Não encostar cabo nas laterais do sensor

PCB v1.0: Verificar se pino Vout do sensor de corrente está conectado. Pode estar desconectado - soldar jumper se necessário.

### Passo 5: Entrada de Segurança (Opcional)

- Conectar pino D7 à saída de segurança da ECU (se disponível)
- Sinal +5V no D7 = bomba desliga imediatamente
- Útil para corte de combustível, anti-lag, limitador, etc

## 5. Checklist Pré-Energização

Verificar ANTES de conectar bateria:

? | Item
? | Todos os cabos com seção adequada (4 AWG alimentação, 10 AWG bombas)
? | Fusíveis 60A instalados (1x alimentação + 2x bombas = 3 fusíveis)
? | GND conectado em ponto limpo do chassi (sem tinta/ferrugem)
? | Polaridade correta em todos os sensores (usar multímetro)
? | Sensores de corrente na direção correta (seta aponta bateria?bomba)
? | Sensor MAP: Pino 1 = Vout, conectores verificados
? | Nenhum fio desencapado encostando em metal
? | Bombas temporariamente desconectadas (teste sem carga primeiro)

## 6. Primeiro Teste

### Teste 1: Energização (sem bombas)

1. Com bombas DESCONECTADAS, reconectar bateria
2. LED deve acender AZUL por 2 segundos
3. Depois LED muda para outra cor (baseado na pressão detectada)
4. Se LED não acender: verificar alimentação e fusíveis

### Teste 2: Sensor MAP

- Soprar levemente na mangueira do MAP
- LED deve responder (mudar intensidade/cor)
- Se não responder: verificar conexão do sensor

### Teste 3: Com Bomba

- Conectar UMA bomba primeiro (canal 1)
- Bomba deve operar (ouvir ruído)
- Potência varia conforme pressão no sensor MAP
- Se LED ficar vermelho: corrente alta (verificar bomba/fiação)

Corrente típica: Bombas normais consomem 8-25A. Se passar de 30A constantemente, há problema (curto, bomba travada, etc).

## 7. Operação Normal

### Comportamento Esperado

- Motor desligado/marcha lenta: Bomba em 70% (economia)
- Acelerando/sob carga: Bomba vai até 100% conforme necessidade
- LED verde: Tudo normal
- LED amarelo/laranja ocasional: Normal sob carga alta
- LED vermelho constante: Problema - investigar

### Ajustes (se necessário)

Para alterar faixas de pressão ou thresholds de corrente, editar arquivo Config.h no código e regravar Arduino:

- Pressão baixa: MAP_BAR_LOW_SETPOINT = 0.4
- Pressão alta: MAP_BAR_HIGH_SETPOINT = 0.6
- Limite corrente WARNING: CURRENT_THRESHOLD_WARNING = 25.0

## 8. Solução de Problemas

Sintoma | Causa Provável | Solução
LED não acende | Sem alimentação | Verificar fusíveis, +12V e GND
Bomba não funciona | Sem sinal PWM ou MOSFET | Verificar conexões de potência da bomba
LED sempre vermelho | Corrente muito alta | Verificar bomba (travada?) e fiação (curto?)
Bomba 100% sempre | Sensor MAP desconectado | Verificar 3 fios do sensor e mangueira
Sistema instável | GND ruim | Refazer conexão GND em ponto limpo

Se LED vermelho constante E bomba quente: DESLIGUE imediatamente! Curto-circuito ou falha grave.

## 9. Manutenção

### Mensal

- Verificar aperto de terminais
- Limpar poeira da placa (ar comprimido)
- Verificar mangueira do MAP (rachaduras/vazamentos)
- Testar fusíveis com multímetro

### Semestral

- Substituir fusíveis preventivamente
- Verificar aquecimento dos componentes
- Testar sistema de proteção (simular sobrecarga)

## 10. Avisos de Segurança

- ?? Sistema trabalha com correntes LETAIS (até 50A)
- ?? Instalação incorreta pode causar INCÊNDIO
- ?? Combustível é ALTAMENTE INFLAMÁVEL
- ?? Usar SEMPRE fusíveis de 60A (não substituir por maior)
- ?? GND deve ter baixa impedância (cabo grosso, chassi limpo)

Em caso de dúvida, consulte profissional qualificado. Não arrisque sua segurança.

### Contato para Suporte

- ?? Documentação completa: README.md no projeto
- ?? Esquemático: pcb/EvoProject 1.0.pdf
- ?? Dúvidas técnicas: Consultar desenvolvedor

PumpControl v2.0 - Manual de Instalação Simplificado

Firmware: Sistema de Proteção Avançado | Janeiro 2026

?? Este equipamento não é certificado para uso em via pública. Uso por sua conta e risco.

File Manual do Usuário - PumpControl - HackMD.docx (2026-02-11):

Manual do Usuário - Controle de bomba

# Especificações Técnicas

## Alimentação

Tensão de entrada: 8-16V DC (sistema automotivo)

Consumo: Variável conforme carga conectada

## Sensor de Pressão (MAP)

Range de operação: 15-700 kPa absoluto (0.15 - 7bar) (gauge/relativo)

Tipo: MPX5700AP (pressão absoluta, convertida para gauge)

## Saídas PWM

Canais: 2 saídas independentes

Controle: Percentual da tensão de alimentação

Pressão baixa (0.4 bar): 70% da tensão de entrada

Pressão alta (0.6 bar): 100% da tensão de entrada

Valores intermediários: interpolação linear

## Monitoramento de Corrente

Canais: 2 sensores independentes (ACS772LCB-050B)

Range: 0-45A Máxima medida pelo sensor por canal (unidirecional)

# Conector de Interface


## Pinagem do Conector - vista traseira

Pino | Sinal
1 | VCC
2 | GND
3
4
5
6
7 | Entrada PWM para modo slave
8
9
10
11
12
13
14
15 | Sinal de Proteção (desliga saída)
16


+12 = +Bateria

S1 S2 = Saída para bomba 1 e 2 - acionamento por negativo

GND = Negativo bateria

# Sistema de Proteção por Corrente

O sistema possui proteção progressiva que nunca desliga completamente a bomba (crítico para motor em funcionamento).

## Níveis de Proteção

Corrente

Nível

Ação

Redução de Potência

0-25

A

NORMAL

Operação normal

0

% (potência plena

)

25-30

A

WARNING

Alerta inicial

30

% de redução

30-35

A

HIGH

Corrente alta

40

% de redução

35-40

A

CRITICAL

Corrente crítica

50

% de redução

>40

A

FAULT

Falha detectada

50

% mantido (mínimo seguro

)

>45

A

EMERGENCY

Emergência

Desligamento completo*

*EMERGENCY: Indica curto-circuito ou sobrecarga severa (sensor próximo ao limite de

50

A

)

# Indicação Visual - LED RGB

O LED indica o estado do sistema em tempo real pela cor e comportamento:

## Cores Sólidas (operação normal)

Cor

Significado

Verde

Corrente baixa (0-25A) - operação normal

Verde→Amarelo

Corrente moderada (25-30A) - entrando em warning

Amarelo→Laranja

Corrente elevada (30-35A) - proteção ativa

Laranja→Vermelho

Corrente alta (35-40A) - proteção crítica

## Piscando (situações críticas)

Comportamento

Significado

Ação Necessária

Pisca lento

(1Hz)

FAULT - Corrente >40A

Verificar carga/fiação

Pisca rápido

(5Hz)

EMERGENCY - Corrente >45A

Verificar curto-circuito

Pisca azul

(2Hz)

Desligamento por segurança externa

Verificar entrada D8

# Entrada de Segurança Externa Pino 15

## Função

Permite que sistemas externos (ECU, relé de segurança, etc.) desliguem imediatamente as saídas.

## Configuração

Pino: 15 (ativo em LOW - pull-up interno)

Ação: Quando ativada, força saídas para 0V imediatamente

Indicação: LED pisca em azul enquanto ativa

## Comportamento

Quando a entrada de segurança é acionada:

1. Saídas PWM vão para 0% instantaneamente (sem rampa)
2. LED pisca em azul
3. Mensagem no serial: "EXTERNAL SAFETY ACTIVE"
4. Sistema retoma operação normal quando entrada é liberada

# Entrada de Segurança Externa Pino 7

## Função

Conectar PWM de entrada, ligado na saída de uma ECU externa para que a placa atue como slave, somente reproduzindo o PWM de entrada nas duas saídas

## Configuração

Pino: 7 - PWM 25Hz

Ação: Quando tiver sinal de PWM no pino 7 entra em modo slave.

Indicação:

## Comportamento

Ao detectar PWM na entrada 7, entra em modo slave, onde reproduz o mesmo sinal nas duas saídas S1 e S2.

# Observações Importantes

## ⚠ Proteção Crítica

O sistema NUNCA desliga completamente a bomba em níveis NORMAL-FAULT

Apenas em EMERGENCY (>45A) ocorre desligamento completo

Proteção progressiva reduz corrente gradualmente

## 🔧 Operação Normal

LED verde = tudo OK

Transição de cores = sistema adaptando à carga

Corrente típica: 15-25A em operação normal

## 🚨 Atenção Necessária

LED piscando vermelho = verificar carga e fiação

LED piscando azul = entrada de segurança ativa

Corrente >30A = investigar causa

## 📊 Adaptação Automática

Sistema ajusta saída baseado em:

1. Pressão MAP (0.4-0.6 bar)
2. Tensão de alimentação (8-16V)
3. Corrente monitorada (proteção)

Saída é sempre um percentual da tensão de entrada

Exemplo: 80% em 12V = 9.6V / 80% em 14V = 11.2V

# Resumo - O que Observar

✅ Normal: LED verde sólido, corrente <25A

⚠ Atenção: LED amarelo/laranja, corrente 25-35A

🔴 Crítico: LED vermelho ou piscando, corrente >35A

🔵 Segurança: LED azul piscando, entrada 15 ativa

file:///C:/Users/lucas.faria/Downloads/Manual do Usuário - PumpControl.html 1/5

02/02/2026, 19:49 Manual do Usuário - PumpControl - HackMD

02/02/2026, 19:49 Manual do Usuário -

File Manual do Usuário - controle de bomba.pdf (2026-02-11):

02/02/2026, 19:49 | Manual do Usuário -
file:///C:/Users/lucas.faria/Downloads/Manual do Usuário - PumpControl.html | 1/7

## Manual do Usuário - Controle de bomba

## Especificações Técnicas

Alimentação

Tensão de entrada: 8-16V DC (sistema automotivo)

Consumo: Variável conforme carga conectada

Sensor de Pressão (MAP)

Range de operação: 15-700 kPa absoluto (0.15 - 7bar) (gauge/relativo)

Tipo: MPX5700AP (pressão absoluta, convertida para gauge)

Saídas PWM

Canais: 2 saídas independentes

Controle: Percentual da tensão de alimentação

Pressão baixa (0.4 bar): 70% da tensão de entrada

Pressão alta (0.6 bar): 100% da tensão de entrada

Valores intermediários: interpolação linear

Monitoramento de Corrente

Canais: 2 sensores independentes (ACS772LCB-050B)

Range: 0-45A Máxima medida pelo sensor por canal (unidirecional)

## Conector de Interface

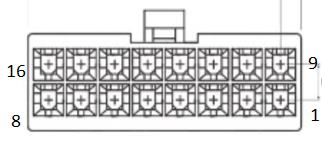
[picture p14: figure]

file:///C:/Users/lucas.faria/Downloads/Manual do Usuário - PumpControl.html | 2/7

Pinagem do Conector - vista traseira
Pino | Sinal
1 | VCC
2 | GND

3

4

5

6

7 | Entrada PWM para modo slave

8

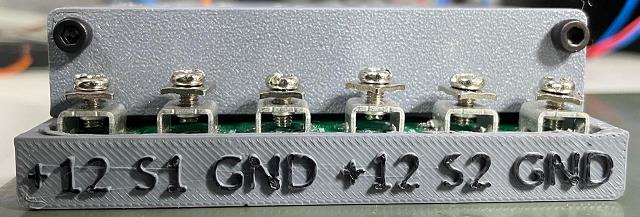
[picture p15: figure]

file:///C:/Users/lucas.faria/Downloads/Manual do Usuário - PumpControl.html | 3/7

9

10

11

12

13

14

15 | Sinal de Proteção (desliga saída)

16

+12 = +Bateria

file:///C:/Users/lucas.faria/Downloads/Manual do Usuário - PumpControl.html | 4/7

S1 S2 = Saída para bomba 1 e 2 - acionamento por negativo

GND = Negativo bateria

## Sistema de Proteção por Corrente

O sistema possui proteção progressiva que nunca desliga completamente a bomba (crítico para motor em funcionamento).

Níveis de Proteção

## Indicação Visual - LED RGB

O LED indica o estado do sistema em tempo real pela cor e comportamento:

Corrente | Nível | Ação | Redução de Potência
0-25A | NORMAL | Operação normal | 0% (potência plena )
25-30A | WARNING | Alerta inicial | 30% de redução
30-35A | HIGH | Corrente alta | 40% de redução
35-40A | CRITICAL | Corrente crítica | 50% de redução
>40A | FAULT | Falha detectada | 50% mantido (mínimo seguro )
>45A | EMERGENCY | Emergência | Desligamento completo*

*EMERGENCY: Indica curto-circuito ou sobrecarga severa (sensor próximo ao limite de

50A)

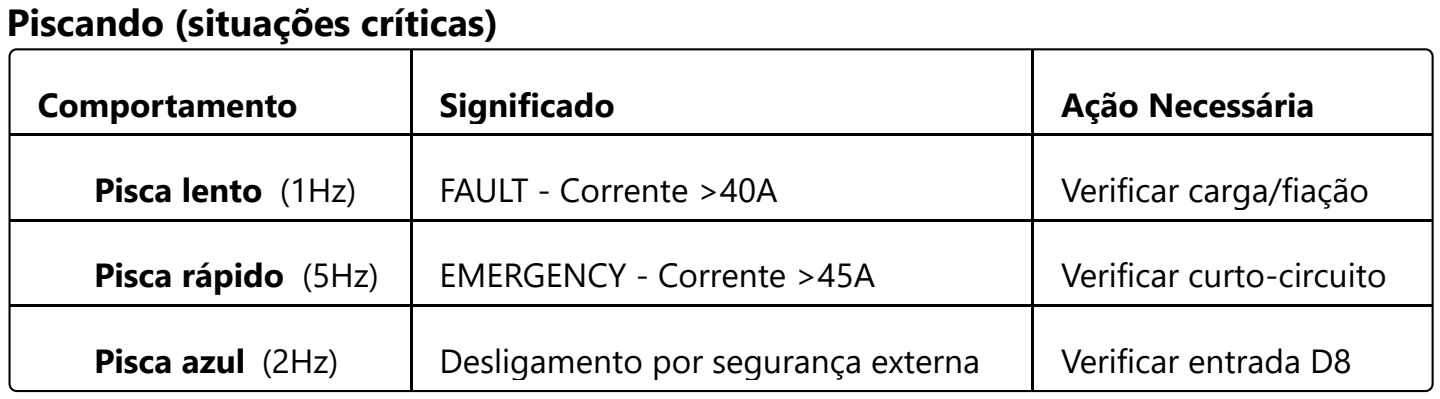
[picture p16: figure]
Piscando (situações críticas); Comportamento; Significado; Ação Necessária; Pisca lento (1Hz); FAULT - Corrente >40A; Verificar carga/fiação; Pisca rápido (5Hz); EMERGENCY - Corrente >45A; Verificar curto-circuito; Pisca azul (2Hz); Desligamento por segurança externa; Verificar entrada D8

file:///C:/Users/lucas.faria/Downloads/Manual do Usuário - PumpControl.html | 5/7

Cores Sólidas (operação normal)

## Entrada de Segurança Externa Pino 15

Função

Permite que sistemas externos (ECU, relé de segurança, etc.) desliguem imediatamente as saídas.

Configuração

Pino: 15 (ativo em LOW - pull-up interno)

Ação: Quando ativada, força saídas para 0V imediatamente

Indicação: LED pisca em azul enquanto ativa

Comportamento

Quando a entrada de segurança é acionada:

1. Saídas PWM vão para 0% instantaneamente (sem rampa)
2. LED pisca em azul
3. Mensagem no serial: "EXTERNAL SAFETY ACTIVE"
4. Sistema retoma operação normal quando entrada é liberada
Cor | Significado
Verde | Corrente baixa (0-25A) - operação normal
Verde→Amarelo | Corrente moderada (25-30A) - entrando em warning
Amarelo→Laranja | Corrente elevada (30-35A) - proteção ativa
Laranja→Vermelho | Corrente alta (35-40A) - proteção crítica

file:///C:/Users/lucas.faria/Downloads/Manual do Usuário - PumpControl.html | 6/7

## Entrada de Segurança Externa Pino 7

Função

Conectar PWM de entrada, ligado na saída de uma ECU externa para que a placa atue como slave, somente reproduzindo o PWM de entrada nas duas saídas

Configuração

Pino: 7 - PWM 25Hz

Ação: Quando tiver sinal de PWM no pino 7 entra em modo slave.

Indicação:

Comportamento

Ao detectar PWM na entrada 7, entra em modo slave, onde reproduz o mesmo sinal nas duas saídas S1 e S2.

## Observações Importantes

⚠ Proteção Crítica

O sistema NUNCA desliga completamente a bomba em níveis NORMAL-FAULT

Apenas em EMERGENCY (>45A) ocorre desligamento completo

Proteção progressiva reduz corrente gradualmente

🔧 Operação Normal

LED verde = tudo OK

Transição de cores = sistema adaptando à carga

Corrente típica: 15-25A em operação normal

🚨 Atenção Necessária

LED piscando vermelho = verificar carga e fiação

LED piscando azul = entrada de segurança ativa

Corrente >30A = investigar causa

file:///C:/Users/lucas.faria/Downloads/Manual do Usuário - PumpControl.html | 7/7

📊 Adaptação Automática

Sistema ajusta saída baseado em:

1. Pressão MAP (0.4-0.6 bar)
2. Tensão de alimentação (8-16V)
3. Corrente monitorada (proteção)

Saída é sempre um percentual da tensão de entrada

Exemplo: 80% em 12V = 9.6V / 80% em 14V = 11.2V

## Resumo - O que Observar

✅ Normal: LED verde sólido, corrente <25A

⚠ Atenção: LED amarelo/laranja, corrente 25-35A

🔴 Crítico: LED vermelho ou piscando, corrente >35A

🔵 Segurança: LED azul piscando, entrada 15 ativa

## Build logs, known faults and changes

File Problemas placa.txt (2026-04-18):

- Invertido CN4 e CN5
- precisa retirar componentes do pino do reset para gravar
- pino vout do sensor map invertido, pino correto é o 1.
- Sensor de corrente montado é o ACS772LCB-050B
- Falta ligar o pino de vout do sensor de corrente
- Retirar trilha de saida de 5V do arduino, para não alimentar a placa pelo USB>
- Pull down gate mosfets
- Pull up saída PWM uC
- RC na entrada dos sensores de corrente.
- Problemas no dimensionamento do diodo de roda livre. esquentando demais.

FW CAN
- Pinos CAN da espera para módulo, não batem com os headers do MCP2515
- Uso da saída PWM de potencia ligada ao D3, causam conflito de timers internos ao usar SPI. Foi necessário trocar para D6 na placa 01.

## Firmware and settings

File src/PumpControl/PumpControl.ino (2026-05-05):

/* ----------------------------------------------------------------------------
   PumpControl.ino - Advanced fuel pump control with current protection
   
   Features:
   - MAP sensor-based pressure control (MPX5700ASX on A4)
   - Dual ACS758LCB-050B current sensors (A2, A3)
   - Current fault protection (never fully shuts down under normal fault)
   - Two PWM outputs (D3, D5) for SSR control
   - NeoPixel RGB LED indicating current level and protection state
   - Serial logging of all parameters

   LED Status Indication:
   - NORMAL (0-40A):   Green solid (gradient green->red as current rises)
   - FAULT (>40A):     Blinking red (1Hz)
   - EMERGENCY (>45A): Fast blinking red (5Hz)

   Protection Strategy:
   - NORMAL (0-40A):   Full voltage available
   - FAULT (>40A):     50% voltage reduction (minimum safe level)
   - EMERGENCY (>45A): Complete shutdown (if enabled)

   CRITICAL SAFETY REQUIREMENT:
   Pump cannot be fully shut down - would damage engine under load.

   Configuration in Config.h
---------------------------------------------------------------------------- */
#include <Arduino.h>
#include "Config.h"
#include "MapSensor.h"
#include "PowerOutputs.h"
#include "CurrentSensor.h"
#include "PowerProtection.h"
#include "VoltageSensor.h"
#include "VoltageProtection.h"
#include "TempSensor.h"
#include "CanInterface.h"
#include "StatusLed.h"
#include "PwmInput.h"

// ============================================================================
// Global instances
// ============================================================================

MapSensor      g_map(Config::PIN_MAP_SENSOR);
PowerOutputs   g_power(Config::PIN_PWM_OUT_1, Config::PIN_PWM_OUT_2);
CurrentSensor  g_curr1(Config::PIN_CURRENT_1);
CurrentSensor  g_curr2(Config::PIN_CURRENT_2);
PowerProtection g_protection(g_curr1, g_curr2);
VoltageSensor  g_voltage(Config::PIN_VCC_SENSE);
VoltageProtection g_voltageProtection(g_voltage);
TempSensor     g_temp(Config::PIN_NTC_TEMP);  // Heatsink NTC 10K (monitoring only)
CanInterface   g_can;  // stub for future CAN bus integration
StatusLed      g_statusLed(Config::PIN_STATUS_LED, Config::STATUS_LED_COUNT);
PwmInput       g_pwmInput(Config::PIN_PWM_INPUT);  // External PWM input source

unsigned long g_lastUpdateMs = 0;
unsigned long g_lastStatusMs = 0;

// ============================================================================
// Pressure to output percentage conversion
// ============================================================================

// Converts pressure (bar) to target output percentage (0.0 to 1.0)
// Linear interpolation between low and high setpoints
// Low pressure (?0.2bar): 70% of supply voltage
// High pressure (?0.4bar): 100% of supply voltage
static float pressureToTargetPercent(float bar) {
    const float pLow  = Config::MAP_BAR_LOW_SETPOINT;
    const float pHigh = Config::MAP_BAR_HIGH_SETPOINT;
    const float percentLow  = Config::OUTPUT_PERCENT_MIN;  // 0.70 (70%)
    const float percentHigh = Config::OUTPUT_PERCENT_MAX;  // 1.00 (100%)

    if (bar <= pLow)  return percentLow;
    if (bar >= pHigh) return percentHigh;

    float spanP = pHigh - pLow;
    float ratio = (bar - pLow) / spanP; // 0..1
    return percentLow + ratio * (percentHigh - percentLow);
}

// ============================================================================
// Setup
// ============================================================================

void setup() {
    Serial.begin(115200);
    // COMPENSATED: millis() runs 64x faster due to Timer 0 prescaler change for PWM
    // 2000ms actual time = 2000 * 64 ticks with modified Timer 0
    while(!Serial && millis() < MILLIS_COMPENSATED(2000)) { 
        // Wait for serial port (optional, for debugging)
    }

    Serial.println(F("========================================"));
    Serial.println(F("  PumpControl with Current Protection  "));
    Serial.println(F("========================================"));
    Serial.println();

    // Initialize all subsystems
    // CRITICAL: Power outputs initialized FIRST to ensure motor starts OFF
    Serial.println(F("Initializing power outputs (motor OFF)..."));
    g_power.begin();  // This sets motor to OFF state with safety delays
    
    Serial.println(F("Initializing sensors..."));
    g_map.begin();
    g_curr1.begin();
    g_curr2.begin();
    g_protection.begin();
    g_voltage.begin();
    g_voltageProtection.begin();
    g_temp.begin();
    g_can.begin(); // stub
    g_pwmInput.begin(); // External PWM input - configures PIN_DIG_IN_1 as INPUT (no pullup)
    
    // Enable PWM debug for first 10 seconds (for troubleshooting)
    // Comment out after confirming PWM detection works
    g_pwmInput.setDebug(true);
    
    Serial.println(F("Initializing status LED..."));
    g_statusLed.begin();

    // Configure digital inputs
    // NOTE: PIN_DIG_IN_2 (D8) is used for external PWM input and configured by g_pwmInput.begin()
    pinMode(Config::PIN_DIG_IN_1, INPUT_PULLUP);     // D7 for external safety (active low - HIGH = OK)

    // Print configuration summary
    Serial.println(F("Configuration:"));
    Serial.print(F("  Pressure: ")); 
    Serial.print(Config::MAP_BAR_LOW_SETPOINT, 2);
    Serial.print(F("-"));
    Serial.print(Config::MAP_BAR_HIGH_SETPOINT, 2);
    Serial.println(F(" bar"));
    
    Serial.print(F("  Voltage:  "));
    Serial.print(Config::OUTPUT_PERCENT_MIN * 100.0f, 0);
    Serial.print(F("-"));
    Serial.print(Config::OUTPUT_PERCENT_MAX * 100.0f, 0);
    Serial.println(F("% of Vsupply"));
    
    Serial.println();
    Serial.println(F("Protection thresholds (A):"));
    Serial.print(F("  FAULT:     ")); Serial.println(Config::CURRENT_THRESHOLD_FAULT, 1);
    Serial.print(F("  EMERGENCY: ")); Serial.println(Config::CURRENT_THRESHOLD_EMERGENCY, 1);
    Serial.println();
    
    Serial.println(F("System ready"));
    Serial.println(F("========================================"));
    Serial.println();
    
    // Additional safety: Keep motor OFF for 2 seconds after full initialization
    // Allows all sensors to stabilize before motor operation begins
    Serial.println(F("Safety delay: Motor OFF for 2 seconds..."));
    g_power.setDuty(0.0f);  // Ensure motor is OFF
    // Using delayMicroseconds because it's NOT affected by Timer 0 prescaler change
    // delay() would require dividing by 64, not multiplying
    delayMicroseconds(2000000UL);  // 2 seconds = 2,000,000 microseconds

    Serial.println(F("Starting normal operation"));
    Serial.println();
}

// ============================================================================
// Main loop
// ============================================================================

void loop() {
    unsigned long now = millis();
    
    // Main control loop - runs at MAIN_LOOP_INTERVAL_MS (20Hz default)
    // Safe millis() rollover handling: subtraction is always safe for unsigned types
    // COMPENSATED: millis() runs 64x faster, so interval must be 64x larger
    if ((unsigned long)(now - g_lastUpdateMs) >= MILLIS_COMPENSATED(Config::MAIN_LOOP_INTERVAL_MS)) {
        g_lastUpdateMs = now;

        // ====================================================================
        // 1. Update PWM input reading (uses pulseIn, may block ~40-100ms)
        // ====================================================================
        if (Config::ENABLE_EXTERNAL_PWM_MODE) {
            g_pwmInput.update();
        }

        // ====================================================================
        // 2. Check external safety input (D8) - HIGHEST PRIORITY
        // ====================================================================
        bool externalSafetyActive = false;
        if (Config::ENABLE_EXTERNAL_SAFETY) {
            int safetyInput = digitalRead(Config::PIN_DIG_IN_1);  // D7
            if (Config::EXTERNAL_SAFETY_ACTIVE_HIGH) {
                externalSafetyActive = (safetyInput == HIGH);  // HIGH = shutdown
            } else {
                externalSafetyActive = (safetyInput == LOW);   // LOW = shutdown
            }

            // If external safety triggered, immediately shutdown and skip normal control
            if (externalSafetyActive) {
                g_power.setDuty(0.0f);  // IMMEDIATE shutdown (no rate limiting)
                g_statusLed.updateExternalSafetyBlink();  // Blue blinking LED
                Serial.println(F("*** EXTERNAL SAFETY ACTIVE - OUTPUT FORCED OFF ***"));
                // Skip rest of control loop - safety has priority
                return;
            }
        }

        // ====================================================================
        // 3. Update current protection (reads currents, applies hysteresis)
        // ====================================================================
        float voltageLimit = g_protection.update();
        PowerProtection::ProtectionLevel protLevel = g_protection.getLevel();
        bool inFault = (protLevel == PowerProtection::ProtectionLevel::FAULT);
        bool inEmergency = (protLevel == PowerProtection::ProtectionLevel::EMERGENCY);

        // ====================================================================
        // 4. Common readings + status LED
        // ====================================================================
        float supplyVoltage = g_voltage.readVoltage();
        g_power.setSupplyVoltage(supplyVoltage);
        g_power.setVoltageLimit(voltageLimit);

        float current1 = g_curr1.readCurrentA();
        float current2 = g_curr2.readCurrentA();
        float maxCurrent = max(current1, current2);
        g_statusLed.updateFromCurrent(maxCurrent, inFault, inEmergency);

        // ====================================================================
        // 5. Source select: External PWM (if valid) vs MAP fallback
        // ====================================================================
        bool externalMode = (Config::ENABLE_EXTERNAL_PWM_MODE && g_pwmInput.isSignalValid());
        float targetPercent;
        float pressureBar = 0.0f;
        if (externalMode) {
            targetPercent = g_pwmInput.getDutyCycle();
        } else {
            g_voltageProtection.update();
            pressureBar = g_map.readPressureBar();
            targetPercent = pressureToTargetPercent(pressureBar);
        }

        // ====================================================================
        // 6. Apply: EMERGENCY overrides source with explicit zero duty
        // ====================================================================
        if (inEmergency) {
            g_power.setDuty(0.0f);
        } else {
            g_power.setOutputPercent(targetPercent);
        }

        // ====================================================================
        // 7. Status line
        // ====================================================================
        if (externalMode) {
            Serial.print(F("*** EXTERNAL PWM MODE *** | PWM In:"));
            Serial.print(g_pwmInput.getDutyCycle() * 100.0f, 1);
            Serial.print(F("% @ "));
            Serial.print(g_pwmInput.getFrequency(), 1);
            Serial.print(F("Hz | "));
        } else {
            Serial.print(F("*** MAP MODE *** | P:"));
            Serial.print(pressureBar, 2);
            Serial.print(F("bar | T%:"));
            Serial.print(targetPercent * 100.0f, 0);
            Serial.print(F("% | Vo:"));
            Serial.print(g_power.getActualOutputVoltage(), 1);
            Serial.print(F("V | "));
        }
        Serial.print(F("Vs:"));
        Serial.print(supplyVoltage, 1);
        Serial.print(F("V | I1:"));
        Serial.print(current1, 1);
        Serial.print(F("A | I2:"));
        Serial.print(current2, 1);
        Serial.print(F("A | Lim:"));
        Serial.print(voltageLimit * 100.0f, 0);
        Serial.print(F("% | "));
        Serial.println(g_protection.getLevelString());
    }
    
    // ========================================================================
    // Detailed status report - runs at STATUS_REPORT_INTERVAL_MS (1Hz default)
    // ========================================================================
    // Safe millis() rollover handling: subtraction is always safe for unsigned types
    // COMPENSATED: millis() runs 64x faster, so interval must be 64x larger
    if ((unsigned long)(now - g_lastStatusMs) >= MILLIS_COMPENSATED(Config::STATUS_REPORT_INTERVAL_MS)) {
        g_lastStatusMs = now;
        
        printDetailedStatus();
    }
    
    // ========================================================================
    // CAN bus polling (stub for future implementation)
    // ========================================================================
    g_can.poll();
}

// ============================================================================
// Status reporting
// ============================================================================

void printDetailedStatus() {
    Serial.println(F("----------------------------------------"));
    Serial.println(F("STATUS REPORT"));
    Serial.println(F("----------------------------------------"));
    
    // External PWM Status
    if (Config::ENABLE_EXTERNAL_PWM_MODE) {
        Serial.print(F("External PWM:    "));
        if (g_pwmInput.isSignalValid()) {
            Serial.println(F("*** ACTIVE ***"));
            Serial.print(F("  Input Duty:    "));
            Serial.print(g_pwmInput.getDutyCycle() * 100.0f, 1);
            Serial.println(F(" %"));
            Serial.print(F("  Input Freq:    "));
            Serial.print(g_pwmInput.getFrequency(), 2);
            Serial.println(F(" Hz"));
            Serial.print(F("  Period:        "));
            Serial.print(g_pwmInput.getPeriodUs() / 1000.0f, 2);
            Serial.println(F(" ms"));
            Serial.print(F("  High Time:     "));
            Serial.print(g_pwmInput.getHighTimeUs() / 1000.0f, 2);
            Serial.println(F(" ms"));
        } else {
            Serial.println(F("Inactive (no signal) - Normal MAP mode"));
            // Debug information
            Serial.print(F("  Pin D7 State:  "));
            Serial.println(g_pwmInput.getCurrentState() == HIGH ? "HIGH" : "LOW");
            Serial.print(F("  Pulses Det:    "));
            Serial.println(g_pwmInput.getPulsesDetected());
            Serial.print(F("  Last Freq:     "));
            Serial.print(g_pwmInput.getFrequency(), 2);
            Serial.println(F(" Hz"));
            Serial.print(F("  Time Since:    "));
            Serial.print(g_pwmInput.getTimeSinceLastPulseMs());
            Serial.println(F(" ms"));
        }
        Serial.println();
    }
    
    // Pressure
    float pressure = g_map.readPressureBar();
    Serial.print(F("Pressure:        ")); 
    Serial.print(pressure, 3);
    Serial.println(F(" bar"));
    
    // Current readings (filtered)
    float i1 = g_curr1.readCurrentA();
    float i2 = g_curr2.readCurrentA();
    Serial.print(F("Current Ch1:     ")); 
    Serial.print(i1, 2);
    Serial.println(F(" A"));
    Serial.print(F("Current Ch2:     ")); 
    Serial.print(i2, 2);
    Serial.println(F(" A"));
    Serial.print(F("Max Current:     ")); 
    Serial.print(max(i1, i2), 2);
    Serial.println(F(" A"));
    
    // Diagnostic: raw voltage readings
    Serial.print(F("Ch1 Voltage:     ")); 
    Serial.print(g_curr1.getFilteredVoltage(), 3);
    Serial.print(F(" V (filtered), "));
    Serial.print(g_curr1.readVoltageRaw(), 3);
    Serial.println(F(" V (raw avg)"));
    Serial.print(F("Ch2 Voltage:     ")); 
    Serial.print(g_curr2.getFilteredVoltage(), 3);
    Serial.print(F(" V (filtered), "));
    Serial.print(g_curr2.readVoltageRaw(), 3);
    Serial.println(F(" V (raw avg)"));
    
    // Supply voltage status
    float supplyV = g_voltage.readVoltage();
    Serial.print(F("Supply Voltage:  ")); 
    Serial.print(supplyV, 2);
    Serial.println(F(" V"));
    Serial.print(F("Voltage Status:  ")); 
    Serial.println(g_voltageProtection.getLevelString());
    Serial.print(F("Sensor Valid:    ")); 
    Serial.println(g_voltageProtection.isSensorOk() ? "YES" : "NO");
    Serial.print(F("V Fault Count:   "));
    Serial.println(g_voltageProtection.getFaultCount());

    // Heatsink temperature (monitoring only, no protection logic)
    float heatsinkC = g_temp.readTemperatureC();
    Serial.print(F("Heatsink Temp:   "));
    Serial.print(heatsinkC, 1);
    Serial.print(F(" °C"));
    if (!g_temp.isSensorOk()) {
        Serial.print(F("  (sensor fault?)"));
    }
    Serial.println();
    Serial.println();
    
    // Current protection status
    Serial.print(F("Protection:      ")); 
    Serial.println(g_protection.getLevelString());
    Serial.print(F("Voltage Limit:   ")); 
    Serial.print(g_protection.getVoltageLimit() * 100.0f, 1);
    Serial.println(F(" %"));
    Serial.print(F("Fault Count:     ")); 
    Serial.println(g_protection.getFaultCount());
    
    // Output status
    float targetPercent = pressureToTargetPercent(pressure);
    float targetV = targetPercent * supplyV;
    Serial.print(F("Target Percent:  ")); 
    Serial.print(targetPercent * 100.0f, 1);
    Serial.println(F(" %"));
    Serial.print(F("Target Voltage:  ")); 
    Serial.print(targetV, 2);
    Serial.println(F(" V"));
    Serial.print(F("Actual Voltage:  ")); 
    Serial.print(g_power.getActualOutputVoltage(), 2);
    Serial.println(F(" V"));
    Serial.print(F("PWM Duty:        "));
    Serial.print(g_power.getCurrentDuty() * 100.0f, 1);
    Serial.println(F(" %"));
    Serial.print(F("Output Source:   "));
    Serial.println((Config::ENABLE_EXTERNAL_PWM_MODE && g_pwmInput.isSignalValid())
                       ? F("EXTERNAL PWM") : F("MAP"));
    
    // External safety status
    if (Config::ENABLE_EXTERNAL_SAFETY) {
        int safetyInput = digitalRead(Config::PIN_DIG_IN_1);
        bool safetyActive = Config::EXTERNAL_SAFETY_ACTIVE_HIGH ?
                           (safetyInput == HIGH) : (safetyInput == LOW);
        Serial.print(F("External Safety: "));
        Serial.println(safetyActive ? "*** ACTIVE (SHUTDOWN) ***" : "OK");
    }

    // Digital inputs
    // Note: D8 (PIN_DIG_IN_2) is used for external PWM input when ENABLE_EXTERNAL_PWM_MODE is true
    bool d1 = (digitalRead(Config::PIN_DIG_IN_1) == LOW);
    Serial.print(F("Digital In 1:    "));
    Serial.println(d1 ? "ACTIVE (LOW)" : "inactive (HIGH)");

    if (Config::ENABLE_EXTERNAL_PWM_MODE) {
        Serial.print(F("Digital In 2:    "));
        Serial.println(F("(used for external PWM input)"));
    } else {
        bool d2 = (digitalRead(Config::PIN_DIG_IN_2) == LOW);
        Serial.print(F("Digital In 2:    "));
        Serial.println(d2 ? "ACTIVE" : "inactive");
    }
    
    // Runtime
    // COMPENSATED: millis() runs 64x faster, divide by prescaler factor for real time
    Serial.print(F("Uptime:          ")); 
    Serial.print(millis() / (1000UL * Config::TIMER0_PRESCALER_FACTOR));
    Serial.println(F(" s"));
    
    Serial.println(F("----------------------------------------"));
    Serial.println();
}

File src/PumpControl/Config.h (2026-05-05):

#pragma once

// -----------------------------------------------------------------------------
// Config.h - Compile-time configuration constants for Pump Control project
// -----------------------------------------------------------------------------
// Adjust setpoints, thresholds, and operational parameters here.
// Nothing is user-configurable at runtime.
// -----------------------------------------------------------------------------

namespace Config {
    // =========================================================================
    // MAP SENSOR & PRESSURE CONTROL
    // =========================================================================
    
    // MPX5700AP - Absolute pressure sensor (15-700 kPa absolute)
    // Sensor reads absolute pressure, converted to gauge (relative to atmosphere)
    // Gauge pressure = Absolute pressure - Atmospheric pressure
    // Verified: 833mV @ atmospheric conditions = 1.013 bar absolute = 0 bar gauge
    
    // Atmospheric pressure at sea level (for absolute?gauge conversion)
    constexpr float ATMOSPHERIC_PRESSURE_BAR = 1.013f; // bar (101.3 kPa)
    
    // Pressure setpoints (bar gauge - relative to atmospheric)
    // Negative values = vacuum (intake manifold below atmospheric)
    // Positive values = boost (turbo pressure above atmospheric)
    // Pressure (bar gauge) where output should be at OUTPUT_PERCENT_MIN
    constexpr float MAP_BAR_LOW_SETPOINT  = 0.4f; // bar gauge (low pressure)
    // Pressure (bar gauge) where output should be at OUTPUT_PERCENT_MAX
    constexpr float MAP_BAR_HIGH_SETPOINT = 0.6f;  // bar gauge (high pressure)

    // Target output as percentage of measured supply voltage
    // This makes the system adaptive to voltage variations (8-14.5V automotive range)
    // Low pressure (?0.2bar): 50% of Vsupply (e.g., 7V @ 14V, 6V @ 12V)
    // High pressure (?0.4bar): 100% of Vsupply (e.g., 14V @ 14V, 12V @ 12V)
    // Intermediate pressures: linear interpolation between 50% and 100%
    constexpr float OUTPUT_PERCENT_MIN = 0.50f; // 50% of supply voltage
    constexpr float OUTPUT_PERCENT_MAX = 1.00f; // 100% of supply voltage (full power)

    // MAP sensor filter coefficient (EMA)
    constexpr float MAP_FILTER_ALPHA   = 0.15f; // 0<alpha<=1 (smaller = smoother)

    // =========================================================================
    // CURRENT SENSING - ACS758LCB-050B (BIDIRECTIONAL)
    // =========================================================================

    // ACS758LCB-050B Hall-effect current sensor specifications
    // Bidirectional variant: ±50A range, nominal zero = Vcc/2, sensitivity = 40mV/A
    // Calibration on this board — two loaded points on scope (after RC filter):
    //   - 1.32A input = 2.54V output
    //   - 2.30A input = 2.58V output
    // Slope = (2.58-2.54)/(2.30-1.32) = 40.8 mV/A ≈ nominal 40 mV/A ✓
    // Zero derived from slope (not measured — Voe offset made direct 0A reading ~22mV high):
    //   Vzero = 2.54 - 1.32*0.04 = 2.488V (matches 2.58 - 2.30*0.04 = 2.488V)
    // This offset is within the ±60mV Voe spec of the datasheet.
    // Negative currents (reverse flow) are clamped to 0 in CurrentSensor.
    constexpr float ACS758_SENSITIVITY = 0.04f;        // V/A (40mV/A for 050B bidirectional)
    constexpr float ACS758_ZERO_CURRENT_V = 2.49f;    // Volts (derived @ 0A - calibrate per board)
    constexpr float ACS758_MAX_CURRENT = 50.0f;        // Amperes (sensor absolute max)
    
    // ADC configuration
    constexpr float ADC_REFERENCE_VOLTAGE = 5.02f;      // Volts (measured at module 5V pin, fed by DCDC)
    
    // Multi-sample averaging to filter PWM noise
    // PWM at 3.9kHz creates ~256us period
    // 32 samples with 50us delay ≈ 4.9ms window = ~19 PWM cycles (good averaging)
    constexpr uint8_t CURRENT_ADC_SAMPLES = 32;         // Number of ADC samples to average
    constexpr uint8_t CURRENT_ADC_DELAY_US = 50;        // Delay between samples (microseconds)
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

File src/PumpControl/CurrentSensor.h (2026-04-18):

#pragma once
#include <Arduino.h>
#include "Config.h"

// -----------------------------------------------------------------------------
// CurrentSensor - Measures current using ACS758LCB-050B Hall-effect sensor
// -----------------------------------------------------------------------------
// ACS758LCB-050B Specifications:
//   - Bidirectional: -50A to +50A measurement range
//   - Sensitivity: 40mV/A (0.040 V/A)
//   - Zero current output: Vcc/2 (~2.5V nominal; calibrated per-board in Config)
//   - Supply voltage: 5V
//   - Output voltage range: 0.5V (-50A) to 4.5V (+50A) around Vzero
//
// Output voltage formula: Vout = Vzero + (I * Sensitivity)
// Current calculation:    I = (Vout - Vzero) / Sensitivity
//
// Note: reverse current (I < 0) is clamped to 0 — the pump load is unidirectional.
//
// PWM interference mitigation:
//   - Multi-sample averaging (configurable via Config::CURRENT_ADC_SAMPLES)
//   - EMA filtering for additional smoothing
//   - Samples taken with microsecond delays to average PWM cycles
// -----------------------------------------------------------------------------
class CurrentSensor {
public:
    explicit CurrentSensor(uint8_t pin) 
        : _pin(pin)
        , _filteredVoltage(Config::ACS758_ZERO_CURRENT_V)
        , _initialized(false)
    {}

    void begin() {
        pinMode(_pin, INPUT);
        
        // Initialize filter with first reading to avoid startup transient
        int adc = analogRead(_pin);
        _filteredVoltage = adcToVoltage(adc);
        _initialized = true;
    }

    // Returns instantaneous current in Amperes (with multi-sample averaging and EMA filtering)
    float readCurrentA() {
        // Multi-sample averaging to filter PWM noise
        // Takes multiple ADC readings with small delays to average out PWM cycles
        float voltage = readVoltageAveraged();
        
        // Apply Exponential Moving Average filter for additional noise reduction
        if (_initialized) {
            _filteredVoltage = (Config::CURRENT_FILTER_ALPHA * voltage) + 
                              ((1.0f - Config::CURRENT_FILTER_ALPHA) * _filteredVoltage);
        } else {
            _filteredVoltage = voltage;
            _initialized = true;
        }
        
        // Calculate current: I = (Vout - Vzero) / Sensitivity
        float current = (_filteredVoltage - Config::ACS758_ZERO_CURRENT_V) /
                        Config::ACS758_SENSITIVITY;

        // Clamp negative (reverse-flow) readings; pump load is unidirectional
        if (current < 0.0f) current = 0.0f;
        if (current > Config::ACS758_MAX_CURRENT) current = Config::ACS758_MAX_CURRENT;
        
        return current;
    }

    // Returns raw unfiltered current (single sample, for diagnostics)
    float readCurrentRawA() {
        int adc = analogRead(_pin);
        float voltage = adcToVoltage(adc);
        float current = (voltage - Config::ACS758_ZERO_CURRENT_V) /
                        Config::ACS758_SENSITIVITY;
        if (current < 0.0f) current = 0.0f;
        if (current > Config::ACS758_MAX_CURRENT) current = Config::ACS758_MAX_CURRENT;
        return current;
    }
    
    // Returns averaged voltage reading (for diagnostics)
    float readVoltageRaw() {
        return readVoltageAveraged();
    }

    // Returns filtered output voltage (for diagnostics)
    float getFilteredVoltage() const {
        return _filteredVoltage;
    }

    // Reset filter (useful after power cycling or fault recovery)
    void resetFilter() {
        _filteredVoltage = readVoltageAveraged();
    }

private:
    uint8_t _pin;
    float _filteredVoltage;  // EMA filtered voltage reading
    bool _initialized;

    // Read voltage with multi-sample averaging to filter PWM interference
    // Takes multiple ADC samples with small delays to average PWM cycles
    // PWM at 977Hz = ~1.02ms period, so 10 samples @ 50�s = 500�s covers ~half cycle
    // SAFETY: uint32_t can hold up to 4,194,303 samples (each ADC read max 1023)
    // Current CURRENT_ADC_SAMPLES=10 is safe. Max safe value = 4194 samples.
    float readVoltageAveraged() {
        uint32_t adcSum = 0;
        
        for (uint8_t i = 0; i < Config::CURRENT_ADC_SAMPLES; i++) {
            adcSum += analogRead(_pin);
            if (i < Config::CURRENT_ADC_SAMPLES - 1) {
                delayMicroseconds(Config::CURRENT_ADC_DELAY_US);
            }
        }
        
        float avgAdc = adcSum / (float)Config::CURRENT_ADC_SAMPLES;
        return adcToVoltage(avgAdc);
    }

    // Convert ADC reading to voltage
    // Arduino ADC: 10-bit (0-1023), reference voltage configurable
    inline float adcToVoltage(float adc) const {
        return (adc / 1023.0f) * Config::ADC_REFERENCE_VOLTAGE;
    }
};

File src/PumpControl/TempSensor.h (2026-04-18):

#pragma once
#include <Arduino.h>
#include <math.h>
#include "Config.h"

// -----------------------------------------------------------------------------
// TempSensor - Heatsink temperature via NTC 10K thermistor
// -----------------------------------------------------------------------------
// Hardware (see Config.h for full schematic):
//   +5V -- R_PULLUP --+-- NTC -- GND
//                     +-- ADC pin (high-impedance via R20)
//
// Beta equation:
//   1/T = 1/T25 + (1/B) * ln(R_NTC / R25)
//   T_celsius = T_kelvin - 273.15
//
// Monitoring only - no protection logic.
// -----------------------------------------------------------------------------

class TempSensor {
public:
    explicit TempSensor(uint8_t pin)
        : _pin(pin)
        , _filteredTempC(25.0f)
        , _initialized(false)
    {}

    void begin() {
        pinMode(_pin, INPUT);
        int adc = analogRead(_pin);
        _filteredTempC = adcToCelsius(adc);
        _initialized = true;
    }

    // Returns heatsink temperature in Celsius (with EMA filtering)
    float readTemperatureC() {
        int adc = analogRead(_pin);
        float tempC = adcToCelsius(adc);

        if (_initialized) {
            _filteredTempC = (Config::TEMP_FILTER_ALPHA * tempC) +
                             ((1.0f - Config::TEMP_FILTER_ALPHA) * _filteredTempC);
        } else {
            _filteredTempC = tempC;
            _initialized = true;
        }
        return _filteredTempC;
    }

    float getFilteredTemperatureC() const {
        return _filteredTempC;
    }

    // Sensor sanity check: ADC near 0 = NTC short to GND, near 1023 = open circuit
    bool isSensorOk() const {
        return _filteredTempC > -40.0f && _filteredTempC < 150.0f;
    }

private:
    uint8_t _pin;
    float _filteredTempC;
    bool _initialized;

    float adcToCelsius(int adc) const {
        // Guard against open/shorted sensor (avoid div-by-zero / log(0))
        if (adc <= 0)    return 150.0f;   // NTC shorted -> very high temp reading
        if (adc >= 1023) return -40.0f;   // NTC open    -> very low  temp reading

        // Divider supply and ADC reference are the same +5V rail -> cancels out
        float rNtc = Config::NTC_R_PULLUP * (float)adc / (float)(1023 - adc);

        float invT = (1.0f / Config::NTC_T25_KELVIN) +
                     (1.0f / Config::NTC_BETA) * log(rNtc / Config::NTC_R25);
        float tKelvin = 1.0f / invT;
        return tKelvin - 273.15f;
    }
};

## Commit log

2026-01-17 Proteção de corrente implementada
2026-01-17 ajuste de escrita
2026-01-17 Correções para compilar
2026-01-19 parametros do sensor de corrente ajustados
2026-01-19 leitura de tensão de alimentação e ajuste MAP
2026-01-19 mudança na logica de set de saida
2026-01-23 Melhorada leitura de corrente - proteção de curto - Invertido PWM - Aumentado frequencia
2026-01-24 Implementado LED de status RGB
2026-02-02 Alterado comportamento do led
2026-02-03 implementado modo slave onde segue PWM de entrada
2026-02-17 retirado proteções de corrente
2026-02-17 relatorio de analise termica
2026-02-28 alterado saida inicial para 50% de pwm
2026-03-21 commit inicial logica por temp
    [430451600.stp, Arduino_Nano_SuperMicro.step, Arduino_Nano_SuperMini.stp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]
2026-03-22 Corrigida a saída PWM e lógica CAN funcional
    [Config.h, MapSensor.h, PowerOutputs.h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]
2026-03-22 alterado pino de saída PWM 1 para D6 para evitar conflito com Timer 0
2026-04-18 adicionado notas sobre configuração de sensores e ajustes de pinos PWM
2026-04-18 projeto de hardware atualizado
    [BM_No Variation.xlsx, BM_Versão Slave.csv, BM_Vers╞o Slave.csv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]
2026-04-18 atualizado comentários sobre pinos analógicos para referência futura
2026-05-05 restaura controle MAP-based no main; versão CAN segue em develop-TempControl
    O merge de develop-TempControl trouxe board adequations (schematics
    EvoProject 1.0 / 2.0, doc do conflito SPI/Timer 2, PowerOutputs sem
    Timer 2 morto) que devem ser comuns aos dois branches, mas também
    trouxe a reescrita do controle de master de MAP para CAN/temperatura,
    que é específica do branch CAN.
    Este commit reverte os arquivos MAP-específicos para o estado original
    do main (2f0e904) e remove o tool CAN-only:
    - src/PumpControl/PumpControl.ino: master = pressureToTargetPercent
    via MapSensor em A4
    - src/PumpControl/Config.h: setpoints MAP_BAR_LOW/HIGH, OUTPUT_PERCENT
    50%-100% (bomba não pode desligar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
    [Config.h, MapSensor.h, PumpControl.ino]
2026-05-05 adicionado handoff Hi-Z para slave mode + boot hold-off + override de EMERGENCY
    A placa agora tem R30 (1K) somando com R28 (1K) na base de T4, então o
    PWM externo e o do uC competem em divisor 1:1 quando ambos drivam. Em
    slave mode os pinos D5/D6 do uC vão para Hi-Z (pinMode INPUT) e o sinal
    externo controla o gate sozinho. No retorno para master, drive HIGH
    antes de pinMode OUTPUT evita glitch de motor full durante a transição.
    Inclui:
    - PowerOutputs::setHiZ()/isHiZ() com sequência segura de transição
    (pego do branch develop-TempControl, idêntico nos dois branches)
    - Boot hold-off no setup para detectar PWM externo já presente antes do
    loop começar a comandar pelo MAP
    - Overr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
    [Config.h, PowerOutputs.h, PumpControl.ino]
2026-05-05 Modo PWM atualizado e documetnação
